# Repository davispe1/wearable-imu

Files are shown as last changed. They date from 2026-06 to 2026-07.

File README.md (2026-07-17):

# Wearable IMU — Project Master README

> Wearable IMU-based motion-capture system for **live upper-limb pose estimation**.
> Summer research project (IIT Chicago), with the goal of publishing.
>
> Single source of truth for the system architecture, hardware, communication design,
> processing pipeline, and repository structure.

### At a glance

| Node PCB (v1.0) | 5-DOF calibration / teleop rig |
|---|---|
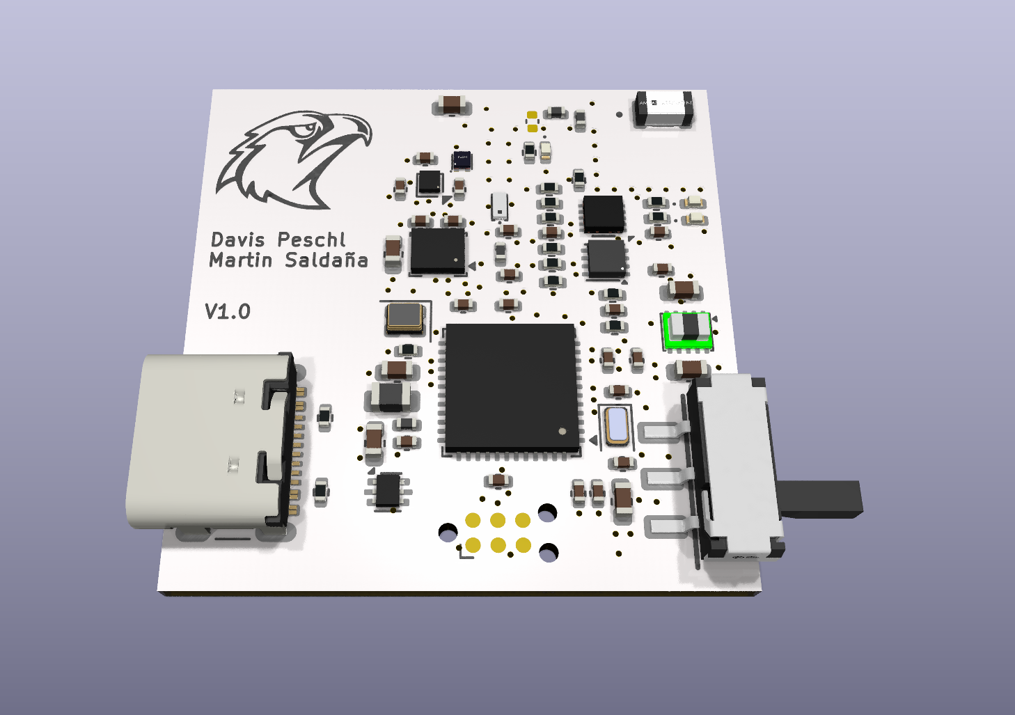
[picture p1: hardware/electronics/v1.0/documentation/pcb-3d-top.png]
PCB 3D top
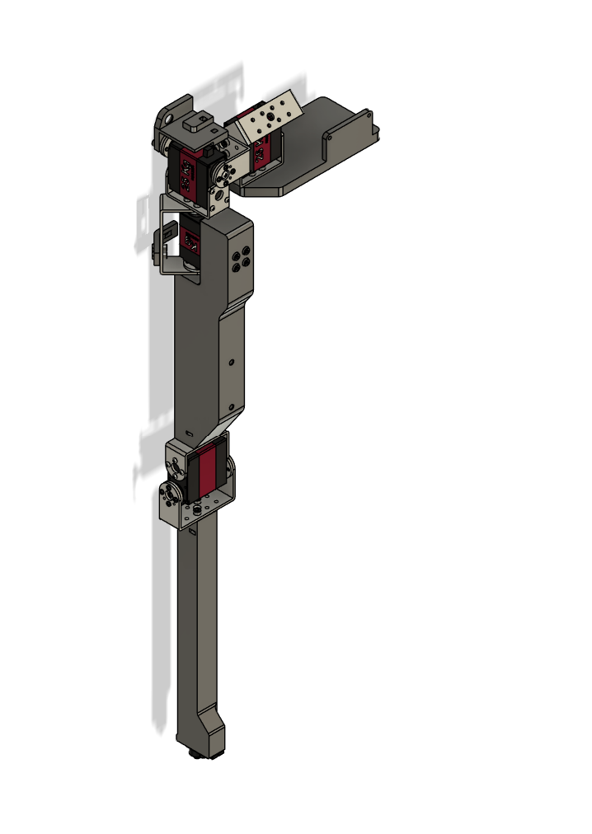
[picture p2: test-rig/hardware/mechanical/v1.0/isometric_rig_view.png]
5-DOF arm rig
|  |  |

**Left:** the wearable IMU node PCB (STM32WB55CEUx + DWM3000 + LSM6DSV16BXTR + BMM350).
**Right:** a separate parallel sub-project, [`test-rig/`](test-rig/README.md) — a
motorised 5-DOF arm used two ways: (1) **teleoperation demo**, driven live from the
wearable nodes, and (2) **calibration / ground truth**, moved through known joint
angles to validate the IMU pipeline's estimated angles against a known reference.

> **New to this project?** The actively maintained TODO / open-work list is
> [`docs/07-roadmap.md`](docs/07-roadmap.md) — start there to see what's done, what's
> open, and what's missing before picking up work.

---

## 1. Project overview

A network of small body-worn **IMU nodes** streams motion data to a **PC**, which reconstructs
and displays a live 3D skeleton of the upper limb. The design philosophy is **thin nodes,
heavy PC**: nodes only sample and transmit; all fusion, kinematics, and visualization run on
the PC — a discrete GPU is recommended for the live 3D visualization but not strictly required.

| Item | Decision (v1) |
|---|---|
| Focus | Upper limb |
| Output | Live joint angles + 3D skeleton visualization |
| Nodes | Scalable design; initial bring-up on **2 confirmed nodes** (wrist, clavicle), a 3rd (chest) possible, scaling to **6–8** |
| Sample rate | **100 Hz** target (hardware capable to 200 Hz) |
| Environment | Lab / bench (PC present in the room) |
| Compute | All heavy processing on the PC, **not** on a body MCU |
| Reference work | *Ultra Inertial Poser* (UIP), SIGGRAPH 2024 — see [References](#10-references) |

---

## 2. System architecture

All nodes use **identical hardware** (STM32WB55CEUx + DWM3000). One node is designated the
**master** purely in firmware. Because the boards are identical, multiple transport
topologies can be tested and compared on the same hardware (a useful experimental result).

### Primary topology

```mermaid
flowchart LR
    subgraph Body["On-body (wearable)"]
        N1["Sensor node 1<br/>WB55CE + DWM3000"]
        N2["Sensor node 2<br/>WB55CE + DWM3000"]
        N3["Sensor node N<br/>WB55CE + DWM3000"]
        M["Master node<br/>WB55CE + DWM3000"]
        N1 -- UWB --> M
        N2 -- UWB --> M
        N3 -- UWB --> M
    end
    M -- "BLE" --> PC["PC<br/>all processing + 3D viewer"]
    M -. "SWD / SWO (wired dev/recovery)" .-> PC
```

- **On-body UWB network** carries node data to the master, provides **time sync**, and
  (phase 2) provides **inter-node ranging** for drift correction.
- **Master node** aggregates all node data and is the single uplink to the PC.
- **PC** runs the full pipeline and the live visualization (stages detailed in [§6](#6-processing-pipeline-pc)).

> **v1 needs no Kalman filter.** Orientation → joint angles → DH skeleton → render is a
> complete working visualization. The EKF (with UWB distances) is a phase-2 enhancement
> for drift and position.

---

## 3. Transports & fallbacks

Every node has **two radios**: UWB for the on-body network (node → master, time sync,
ranging) and BLE for the master's wireless uplink to the PC. Paths to the PC:

| Layer | Path | Role |
|---|---|---|
| Live | BLE (master → PC, **host-native** Bluetooth) | Main wireless link |
| Wired | **SWD / SWO** via ST-LINK, or native USB (CDC) | Bench/dev + data recovery |

Notes:
- BLE uses **serial-over-BLE** (a transparent UART-style GATT service / NUS-equivalent), so
  it behaves like a wireless UART. **Decided: host-native Bluetooth** — the PC's own
  Bluetooth receives it, no extra receiver hardware.
- **Debug/data connection is a TC2030-IDC footprint** — bare pogo-pin pads on the PCB, not a
  soldered connector. A separate Tag-Connect TC2030 cable/clip clamps onto those pads from
  outside the board (to an ST-LINK) to make contact. Carries SWDIO/SWDCLK/SWO; SWO gives a
  one-way MCU→PC data channel (read via SWV tooling).
- **USB-C carries both charging and native USB data** (the WB55CEUx has native USB; a USB
  CDC stack is already in `firmware/USB_Device/`). The bring-up smoke test is likely read
  over this USB-CDC port, not SWO — **needs confirming**, since earlier wording assumed
  SWD/SWO was the only wired data path.
- RAM ring buffer (~seconds) covers jitter/retransmit; a >3–5 s dropout is treated as a
  compromised session regardless, so heavy persistence is unnecessary.

---

## 4. Hardware — Node BOM

Single identical board for every node. The architecturally significant parts:

| Function | Part | Notes |
|---|---|---|
| MCU | **STM32WB55CEUx** (UFQFPN48) | Dual-core: Cortex-M4 @ 64 MHz (application) + Cortex-M0+ @ 32 MHz (radio stack), Bluetooth 5.4 LE + 802.15.4, 512 KB flash, 256 KB SRAM, native USB. Drives DWM3000 over SPI. |
| IMU | **LSM6DSV16BXTR** | 6-axis, onboard SFLP sensor fusion. **I2C1, addr `0x6B`** (SDO pulled high) |
| Magnetometer | **BMM350** | Separate 3-axis → makes the node 9-DOF. **Decided: using it for v1** (not yet implemented in firmware — see [§7](#7-build-phases--roadmap)). **I2C1, addr `0x14`** (ADSEL pulled low) |
| UWB | **DWM3000** | Data transport + sync + (phase-2) inter-node ranging. SPI1 (only SPI sensor on the node — IMU and mag are both I2C) |

Full parts list (power management, connectors, battery, indicator, etc.) is in
[`hardware/electronics/v1.0/README.md`](hardware/electronics/v1.0/README.md#key-parts),
sourced directly from the fabricated board's BOM.

### PC-side hardware

| Function | Part | Notes |
|---|---|---|
| BLE receiver | **PC-native Bluetooth** | No extra receiver hardware |
| Compute | Any PC (a discrete GPU helps for the live 3D visualization, not required) | Runs full pipeline + visualization |

### Node PCB v1.0 — renders & board views

> Full detail (all four copper layers, schematic PDF, fab files) lives in
> [`hardware/electronics/v1.0/`](hardware/electronics/v1.0/README.md).
> Known antenna keepout issue on the DWM3000 — see [§7](#7-build-phases--roadmap) for the
> decision on whether that becomes a v1.1 bug-fix spin or gets folded into a v2.0 redesign,
> pending v1.0 bring-up results. See also
> [`hardware/electronics/CHANGELOG.md`](hardware/electronics/CHANGELOG.md).

| PCB 3D — top | PCB 3D — bottom |
|---|---|
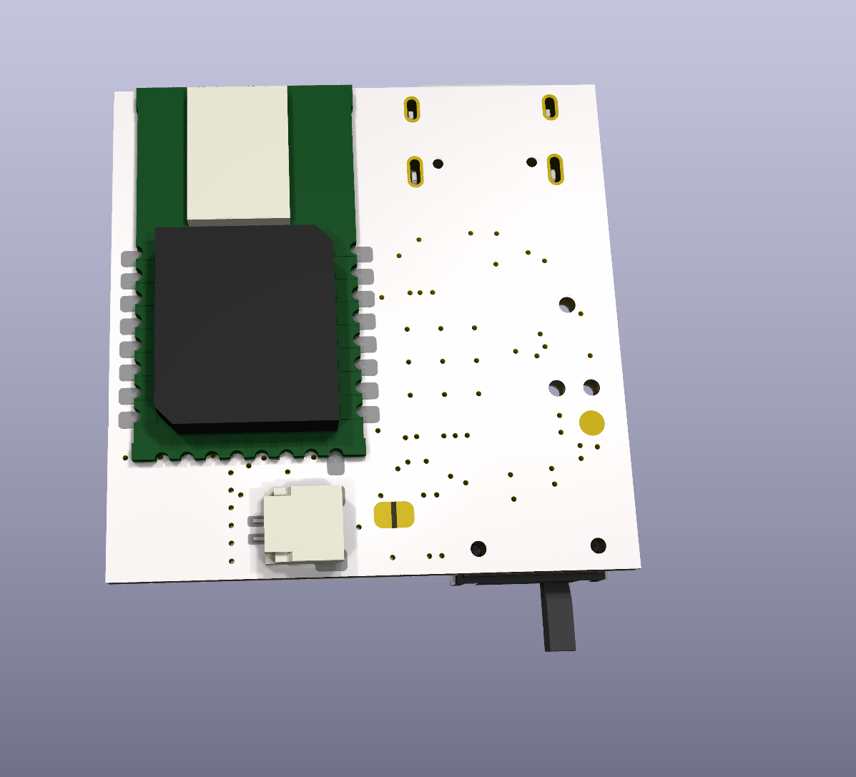
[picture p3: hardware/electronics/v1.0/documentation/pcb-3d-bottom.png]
PCB 3D bottom
| PCB 3D top |  |

| Assembled (exploded) | Worn on wrist |
|---|---|
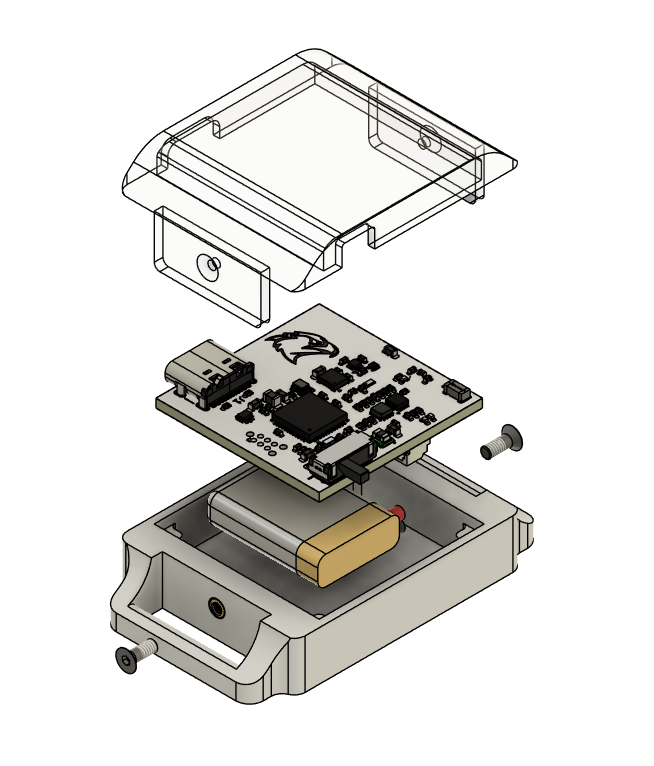
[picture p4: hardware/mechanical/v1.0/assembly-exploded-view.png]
Assembly exploded
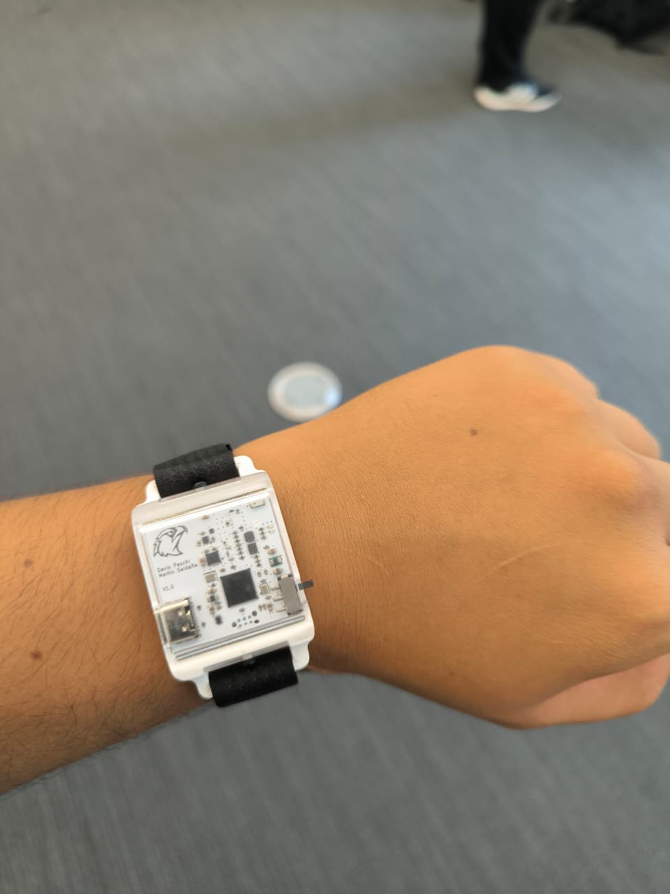
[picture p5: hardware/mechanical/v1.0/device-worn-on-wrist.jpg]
Worn on wrist
|  |  |

---

## 5. Communication & protocols

### Data format (per node, per sample)
- **Option A (preferred for the rig): raw 9-DOF** — accel(3) + gyro(3) + mag(3) + timestamp.
  Maximum flexibility; host does all fusion. ~40 bytes/sample.
- **Option B: SFLP quaternion** (from the LSM6DSV16B) + raw mag. Smaller, less host work.
- **Decision: open** (see [Open items](#11-open-items)). Magnetometer rate can be lower
  (e.g., 50–100 Hz).

> Bandwidth budgeting and UWB TDMA scheduling design used to be spelled out here with
> specific numbers, but neither BLE nor UWB has actually been tested on hardware yet — those
> numbers were pre-hardware-test estimates, not decisions. They now live in
> [`docs/04-firmware.md`](docs/04-firmware.md#tdma-frame-planned--not-implemented) (UWB
> scheduling/sync) and [`docs/03-communication.md`](docs/03-communication.md#6-bandwidth-check)
> (bandwidth), clearly marked as unvalidated estimates rather than settled numbers.

---

## 6. Processing pipeline (PC)

| Stage | Purpose | Maps to known technique |
|---|---|---|
| 0. Calibration | Sensor-to-segment alignment (T/N-pose) | — |
| 1. Orientation filter | accel+gyro(+mag) → world-frame quaternion | complementary / Madgwick / VQF (or use SFLP) |
| 2. Joint angles | relative rotation between adjacent segments | rotation matrices / quaternions |
| 3. EKF (phase 2) | fuse UWB inter-node distances → fix drift / get positions | Kalman filter (new) |
| 4. Forward kinematics | joint angles + segment lengths → 3D skeleton | **Denavit-Hartenberg** |
| 5. Visualization | live render of links/joints | 3D viewer |

- **v1 path:** stages 0 → 1 → 2 → 4 → 5 (no EKF).
- **Phase 2:** insert stage 3 (EKF + UWB ranging) for drift/position.
- A **synthetic data generator** (or arm-simulator rig) can drive the pipeline before
  hardware is ready.

---

## 7. Build phases / roadmap

1. **Firmware + data path** — node sampling, UWB schedule, master aggregation, PC ingest.
   Bring up over **SWD/SWO (wired)** first (familiar tooling), then add BLE as a parallel path.
2. **Visualization program** — orientation → joint angles → DH skeleton → live 3D render.
   Develop against **synthetic data** first. No Kalman filter needed.
3. **EKF** — learn the Kalman filter (from complementary-filter intuition) and fold in the
   UWB inter-node distances for drift/position.

> BLE de-risking: prove the entire system over wired (SWD/SWO) first; learn BLE in isolation
> on a NUCLEO-WB55RG with ST's serial-over-BLE example; then integrate with the wired path
> still available as a safety net.

### Parallel workstream — 5-DOF arm / test rig

A 5-DOF robotic arm mirroring human upper-limb kinematics. It's a single physical
rig serving **two purposes**:

1. **Teleoperation demo** — drive the arm live from the wearable IMU nodes.
2. **Calibration / ground-truth measurement** — move the arm through known joint
   angles and compare against the IMU pipeline's estimated angles, to quantify
   filter error.

5-DOF arm rig

Status: forward kinematics validated (MATLAB GUI); inverse kinematics implemented
but not yet validated; mechanical CAD for the rig itself in progress. Full detail
in [`docs/07-roadmap.md`](docs/07-roadmap.md#parallel-workstream--5-dof-arm-teleoperation--calibration-rig)
and [`test-rig/README.md`](test-rig/README.md).

---

## 8. Repository structure

Actual current tree (not aspirational — status noted per folder):

```
wearable-imu/
├── README.md                      # this file
├── CONTRIBUTING.md                # branch/tag/versioning conventions
├── docs/                          # markdown source of truth, one file per section
│   ├── 01-system-overview.md
│   ├── 02-hardware.md
│   ├── 03-communication.md        # authoritative wire protocol spec
│   ├── 04-firmware.md             # firmware architecture: CubeMX project + smoke test are
│   │                               #   real; packet/comms application layer still planned
│   ├── 05-host-pipeline.md
│   ├── 06-calibration.md
│   ├── 07-roadmap.md              # build phases, real done/not-done status, open items
│   ├── 08-appendices.md
│   └── 09-tools.md                # tools used to build/assemble hardware — incomplete
│
├── firmware/                      # STM32CubeIDE project for the STM32WB55CEUx node
│   ├── Core/                      # CubeMX-generated (HAL, startup, clock) — do not hand-edit
│   ├── Drivers/                   # CMSIS + STM32WBxx HAL
│   ├── Middlewares/ST/            # ST middleware
│   ├── ThirdParty/                # BMM350, lsm6dsv16bx vendor drivers
│   ├── USB_Device/                # USB CDC (virtual COM port) stack — native USB, not charging-only
│   └── *.ioc / *.ld               # CubeMX config + linker scripts
│   (application logic — packet serializer, UWB TDMA, BLE serial, role state
│    machines — not written yet; see docs/07-roadmap.md)
│
├── host/                          # Python package — the live PC pipeline
│   └── wearable_imu/
│       ├── ingest/                # serial / SWO readers + wire protocol codec (real, tested)
│       ├── sync/                  # timebase alignment
│       ├── orientation/           # filters (complementary / Madgwick / VQF) — stub
│       ├── kinematics/            # joint angles + DH forward kinematics — stub
│       ├── ekf/                   # phase 2: UWB-distance fusion — stub
│       ├── viz/                   # 3D skeleton viewer — stub
│       ├── sim/                   # synthetic data generator (real, drives dev without hardware)
│       ├── config.py
│       └── main.py
│
├── hardware/                      # physical design files — only place with version folders
│   ├── electronics/v1.0/          # node PCB: schematic, layout, fab files, renders
│   └── mechanical/v1.0/           # node enclosure: STEP/STL, assembly renders
│
├── simulation/scripts/            # 5-DOF arm kinematics (MATLAB) — FK validated, IK
│                                   # implemented pending validation. Not yet cross-linked
│                                   # into test-rig/ below.
├── test-rig/                      # ground-truth validation rig — mostly planned
│   └── hardware/mechanical/v1.0/  # rig arm CAD — in progress (the only real part so far)
│
├── calibration/                   # calibration routines + saved profiles — planned
└── tools/                         # flash/capture/calibrate/replay scripts — planned
```

---

## 9. Design decisions log (the "why")

- **Sensor selection, generally:** across the BOM, the guiding principle was to pick the
  most capable part available in its class at design time, not the cheapest one that
  technically works — this is a research/publication project, not a cost-optimized
  product, so headroom (accuracy, noise floor, ranging precision) was prioritized over
  BOM cost. The three sensing ICs below were each chosen on that basis:
  - **IMU = LSM6DSV16BXTR:** one of ST's most capable 6-axis parts at selection time —
    onboard SFLP (Sensor Fusion Low Power) hardware fusion can offload orientation
    estimation from the host, but is bypassable for a raw-data path if the host EKF is
    preferred instead. High ODR headroom (only 120 Hz is used here).
  - **Magnetometer = BMM350:** chosen for resolution/noise performance over cheaper
    3-axis parts, making the node 9-DOF. Populated on every board, but use is **optional**
    pending characterization of the lab's magnetic environment — indoor steel/motors can
    make magnetometer data actively worse than leaving it out.
  - **UWB = DWM3000:** the most capable UWB module available for this application —
    supports the newer 802.15.4z standard (better multipath resistance) with strong
    ranging accuracy. Chosen as the **sole radio** on the node: it replaces what would
    otherwise be a separate ranging radio, handling data transport, sub-ns time sync,
    and inter-node ranging in one part.
- **MCU = STM32WB55CEUx** (over the earlier L431 / U535): the master needs BLE; identical
  BLE-capable boards let any node be master and enable topology testing. Dual-core
  (Cortex-M4 app core + Cortex-M0+ radio stack core), ultra-low-power (good for a small
  battery), and has native USB (unlike the STM32WBA55 originally assumed during design —
  see the note in [§3](#3-transports--fallbacks) about reconciling the SWD/SWO-vs-USB wired
  data path now that native USB is actually available).
- **Master-aggregator + single BLE uplink** (vs UIP's per-node BLE): one BLE link instead of
  N (avoids PC multi-link flakiness) and gives tighter on-body sync.
- **BLE for the PC uplink, UWB kept on-body:** the master's single link to the PC is BLE
  (2.4 GHz, more robust to body blocking than UWB's 6.5–8 GHz); UWB is reserved for the
  on-body network — data transport to the master, time sync, and ranging — where it's
  irreplaceable.
- **PC does all heavy compute** (not a body MCU): the pipeline (and future ML) is GPU/
  desktop work, and PC-side iteration is far faster than reflashing firmware.
- **No on-node SD card or flash IC:** RAM buffer only; avoids tedious card extraction, and
  the fabricated v1.0 board doesn't populate a flash chip at all — recovery happens over
  SWD (or USB, pending the reconciliation above).
- **100 Hz for v1:** matches UIP and is sufficient for full-body pose; keeps BLE bandwidth
  comfortable.

---

## 10. References

- **[Ultra Inertial Poser (UIP), SIGGRAPH 2024](https://siplab.org/projects/UltraInertialPoser)**
  (Armani, Qian, Jiang, Holz — [ACM DL](https://dl.acm.org/doi/10.1145/3641519.3657465),
  [arXiv](https://arxiv.org/abs/2404.19541),
  [code](https://github.com/eth-siplab/UltraInertialPoser)) — sparse body-worn IMU + UWB
  inter-node ranging, fused on a host with VQF orientation, per-pair EKF, an LSTM + graph-conv
  network, and a physics dynamics optimizer to produce full-body pose.
  - **This project mirrors** the IMU + UWB sensing approach and the "thin nodes, host does
    the work" philosophy.
  - **This project differs:** adds a magnetometer (9-DOF vs UIP's 6-DoF); uses a
    master-aggregator UWB→BLE topology (vs UIP's per-node BLE to host); focuses on upper-limb
    joint angles + live visualization for v1; EKF/ranging is a phase-2 enhancement.

---

## 11. Open items

**The actively maintained TODO / open-work list lives in
[`docs/07-roadmap.md`](docs/07-roadmap.md)** — its "Open items", "Hardware revisions", and
"Known gaps" sections are the source of truth for what's decided, what's still open, and
what's missing (including firmware, UWB/BLE testing, the test-rig end-effector adapter, and
the onboarding doc for new students). This section is intentionally just a short pointer
rather than a second list, to avoid the two drifting out of sync.

Top-level decisions still open, at a glance:
- **Data format:** raw 9-DOF vs SFLP quaternion + raw mag.
- **Magnetometer:** whether to use it (characterize the lab's magnetic environment first;
  hardware is populated either way).
- **Sample rate:** confirm 100 Hz (vs 200 Hz).

---

## How to use this document

This README and the `docs/` folder are the **markdown source of truth** (versioned in git;
diagrams in **Mermaid** so they edit as text and render on GitHub). For a polished copy for
the team/professor, export markdown → Word/PDF with Pandoc rather than hand-maintaining a
second copy.

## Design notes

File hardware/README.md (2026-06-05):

# hardware/

Physical design files. **This is the only place in the repo with version folders.**

Hardware revisions are discrete fabricated artifacts — you'll have v1.0 boards in hand
while designing v1.1, so both must coexist. Version folders (`v1.0/`, `v1.1/`, …) make
that explicit. Git tags tie a code release to the hardware revision that belongs with it.

## Structure

```
hardware/
├── electronics/
│   ├── v1.0/          ← schematic, layout, BOM, fab files for board rev 1.0
│   └── CHANGELOG.md
└── mechanical/
    ├── v1.0/          ← STEP / STL / CAD files for case rev 1.0
    └── CHANGELOG.md
```

## Adding a new hardware revision

1. Copy the previous version folder (`cp -r v1.0 v1.1`).
2. Make your changes inside `v1.1/`.
3. Add an entry to `CHANGELOG.md`.
4. When a firmware/host release is tied to this hardware rev, create a git tag
   `imu-vX.Y.Z` that documents which hardware folder it targets.

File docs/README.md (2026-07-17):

# docs/

Deep-dive documentation, one file per section. The top-level `README.md` is
the executive summary and source of truth for architecture decisions; these
files expand on each area.

| File | Contents |
|---|---|
| [01-system-overview.md](01-system-overview.md) | Goals, topology, design philosophy |
| [02-hardware.md](02-hardware.md) | Node BOM, host hardware, PCB notes |
| [03-communication.md](03-communication.md) | Protocols, packet formats, bandwidth |
| [04-firmware.md](04-firmware.md) | Firmware architecture, TDMA schedule, drivers |
| [05-host-pipeline.md](05-host-pipeline.md) | Processing stages, orientation filter, DH kinematics |
| [06-calibration.md](06-calibration.md) | T-pose / N-pose procedure, saved profiles |
| [07-roadmap.md](07-roadmap.md) | Build phases, open items, milestones |
| [08-appendices.md](08-appendices.md) | References, glossary, data-sheet links |
| [09-tools.md](09-tools.md) | Tools used to build/assemble the hardware — incomplete |

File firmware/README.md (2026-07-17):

# firmware/

Node firmware for the STM32WB55CEUx. **Git-versioned — no version folders here.**
Use `git tag imu-vX.Y.Z` to mark releases and tie them to a hardware revision.

## Structure

Standard STM32CubeIDE project layout, generated from `wearable IMU.ioc`:

```
firmware/
├── Core/            # CubeMX-generated — do NOT edit by hand; regenerate from .ioc
│   ├── Inc/, Src/, Startup/
├── Drivers/
│   ├── CMSIS/                   # ARM CMSIS
│   └── STM32WBxx_HAL_Driver/    # ST HAL
├── Middlewares/ST/               # ST middleware (e.g. BLE stack support)
├── ThirdParty/
│   ├── BMM350/                  # magnetometer vendor driver
│   └── lsm6dsv16bx/             # IMU vendor driver
├── USB_Device/                   # USB CDC (virtual COM port) stack — the WB55CEUx has native USB
├── *.ld                          # linker scripts
└── wearable IMU.ioc              # CubeMX config (source of truth for Core/)
```

Application logic (role state machines, UWB TDMA, BLE serial, sensor glue,
power management) isn't written yet — only the CubeMX-generated skeleton
exists so far. An earlier scaffolded `App/`, `Comms/`, `Drivers/{dwm3000,
lsm6dsv16b,...}`, `Sensors/`, `Power/` layout was removed in favor of this
generated structure; expect the application code to land inside `Core/Src/`
or new folders alongside it as it's written.

## Bring-up order

1. Generate `Core/` from STM32CubeMX for the STM32WB55CEUx.
2. Bring up SWD/SWO wired link first.
3. Add UWB TDMA (data + sync + ranging).
4. Add BLE serial-over-BLE uplink.

## Building

TODO: STM32CubeIDE project setup. Toolchain: arm-none-eabi-gcc.

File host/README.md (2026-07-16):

# host/

PC-side processing pipeline and 3D visualizer. **Git-versioned — no version folders.**
Tag releases as `imu-vX.Y.Z` alongside the firmware and hardware revision they target.

## Structure

```
host/wearable_imu/
├── ingest/       # serial / BLE / SWO readers → raw sample stream
├── sync/         # multi-node timestamp alignment
├── orientation/  # accel+gyro(+mag) → world-frame quaternion
├── kinematics/   # joint angles + Denavit-Hartenberg forward kinematics
├── ekf/          # phase 2: UWB-distance fusion for drift/position
├── viz/          # live 3D skeleton viewer
├── sim/          # synthetic data generator (develop pipeline without hardware)
├── config.py     # runtime configuration (sample rate, node count, data format …)
└── main.py       # entry point
```

## Setup

```bash
python -m venv .venv
source .venv/bin/activate   # Windows: .venv\Scripts\activate
pip install -r requirements.txt
```

## Running (Phase 1 — ingest path is live)

The protocol/ingest path is stdlib-only, so it runs without installing anything:

```bash
# from host/
py -m wearable_imu.main --sim --seconds 3          # synthetic data through the real codec
py -m wearable_imu.main --sim --capture cap.bin --seconds 5   # write a capture
py -m wearable_imu.main --replay cap.bin           # replay a capture file
py -m wearable_imu.main                             # live: config.TRANSPORT serial port
```

## Tests

```bash
py host/tests/test_protocol.py     # round-trip, fragmentation, resync, golden vector
```

The golden vector in the test is byte-identical to `firmware/.../packet_selftest.c`,
so the firmware and host encoders are locked together.

## Development order (README §7)

1. Drive pipeline with `sim/` synthetic data — no hardware needed.
2. Add `ingest/` SWO reader for wired bring-up.
3. Add `ingest/` BLE reader once firmware BLE is ready.

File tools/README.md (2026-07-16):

# tools/

Utility scripts for flashing, data capture, and calibration.

**Status: planned, not started.** Nothing in this folder is implemented yet;
the table below is the intended scope, not an inventory.

| Script (planned) | Purpose |
|---|---|
| `flash.py` | Flash a node via ST-LINK (wraps openocd / STM32CubeProgrammer) |
| `capture.py` | Capture a raw SWO session to file for offline replay |
| `calibrate.py` | Run the T/N-pose calibration wizard and save a profile |
| `replay.py` | Feed a captured session file through the host pipeline |

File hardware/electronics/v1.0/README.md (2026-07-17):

# electronics / v1.0

Node PCB — revision 1.0. 4-layer board (F.Cu, In1.Cu, In2.Cu, B.Cu).

> **Known issue, fix path pending v1.0 evaluation:** the DWM3000 UWB antenna
> placement doesn't fully follow Qorvo's layout guidelines (clearance/keepout,
> feed line length), which may affect range/link margin. Whether this becomes a
> v1.1 placement-only fix or gets folded into a v2.0 redesign depends on how
> v1.0 performs in bring-up. See `../CHANGELOG.md` and `docs/07-roadmap.md`.

## Contents

- `wearable_IMU.kicad_sch` — schematic (source)
- `wearable_IMU.kicad_pcb` — layout (source)
- `wearable_IMU.kicad_pro` / `.kicad_prl` — project files
- `documentation/` — exported images (below) + `schematic.pdf`
- `jlcpcb/` — fab outputs: `gerber/` (raw Gerbers + drill files), `production_filesV1.0/`
  (BOM, pick-and-place, zipped Gerbers — the JLCPCB submission set), `project.db`
- `fabrication-toolkit-options.json` — KiCad fabrication-toolkit plugin export settings
- The PCB's 3D model (`PCB.step`) lives in `../../mechanical/v1.0/` alongside the
  enclosure — kept in one place instead of duplicated here

Cleaned up (untracked, safe to regenerate/ignore): KiCad's local autosave/history
folders (`.history/`, `.history_trim/` — an embedded git history plugin, ~290 MB),
`wearable_IMU-backups/` (autosave zips), a stale `production/` test export
("prueba1"), an empty `jlcpcb/production_files/`, 0-byte `.rpt` temp files, and
KiCad's `.lck` lock files. Added patterns to `.gitignore` so these don't come back.

## Key parts

Straight from the fabricated board's BOM (`jlcpcb/production_filesV1.0/BOM-wearable_IMU.csv`):

| Function | Part |
|---|---|
| MCU | STM32WB55CEUx |
| IMU | LSM6DSV16BXTR |
| Mag | BMM350 |
| UWB | DWM3000 |
| SMPS | TPSM828224 |
| Charger | BQ25185 |
| Fuel gauge | MAX17048G+T10 |
| Power btn | STM6601BM2DDM6F |

No flash IC is populated — RAM buffering only, no on-node session logging.

## Fabrication

Board fabricated and assembled via **JLCPCB** (PCBA — SMT assembly included, not just bare
board fab). Production files were exported from KiCad using the **fabrication-toolkit**
plugin (`fabrication-toolkit-options.json` holds its export settings).

To re-order or fab a new revision:
1. Open `wearable_IMU.kicad_pro` in KiCad, update as needed.
2. Run the fabrication-toolkit plugin to regenerate `jlcpcb/production_filesV1.0/` (or a new
   `production_filesVX.Y/` for a new revision) — Gerbers, `BOM-wearable_IMU.csv`,
   `CPL-wearable_IMU.csv` (component placement).
3. Upload the zipped Gerbers + BOM + CPL to JLCPCB's PCBA order flow.

## Board renders & layers

**3D views**

| Top | Bottom |
|---|---|
| PCB 3D top | PCB 3D bottom |

**Copper layers** (top → bottom of stack)

| F.Cu (top) | In1.Cu | In2.Cu | B.Cu (bottom) |
|---|---|---|---|
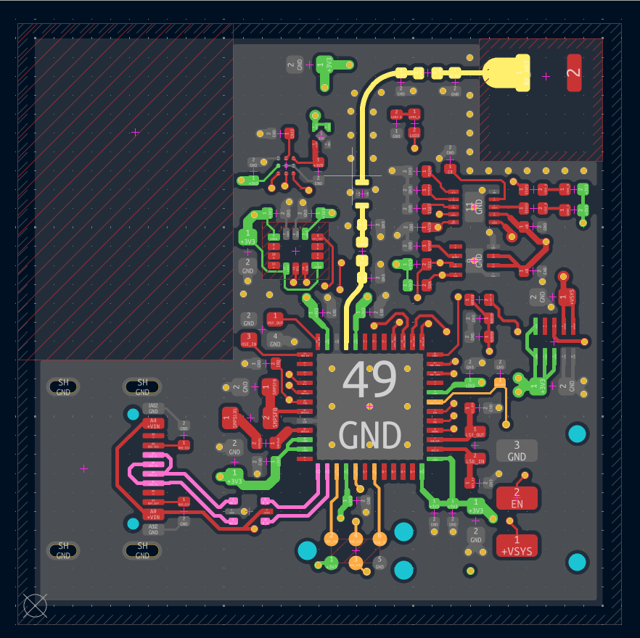
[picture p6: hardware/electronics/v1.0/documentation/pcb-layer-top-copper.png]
Top copper
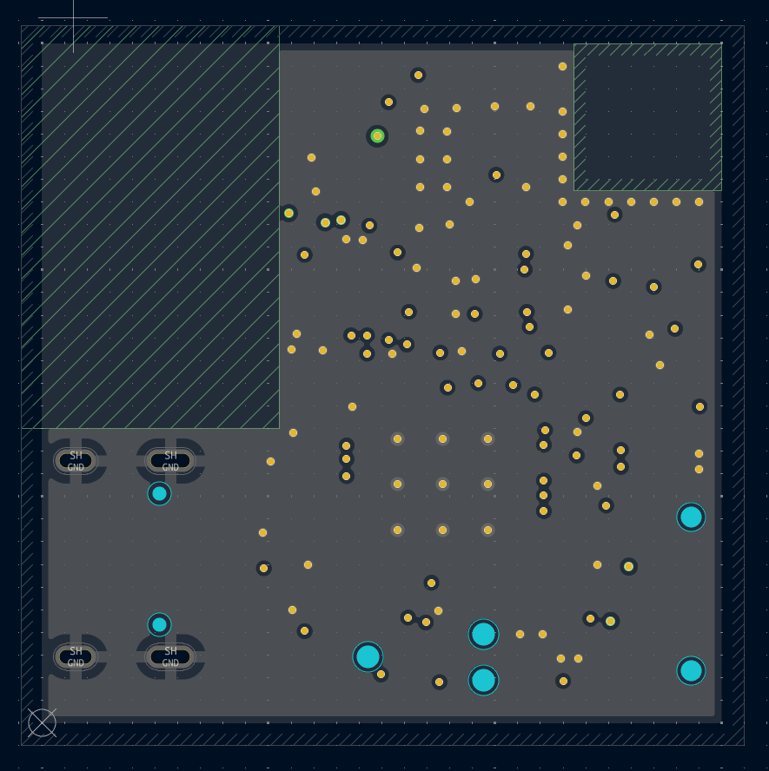
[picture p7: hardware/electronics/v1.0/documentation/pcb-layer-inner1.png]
Inner 1
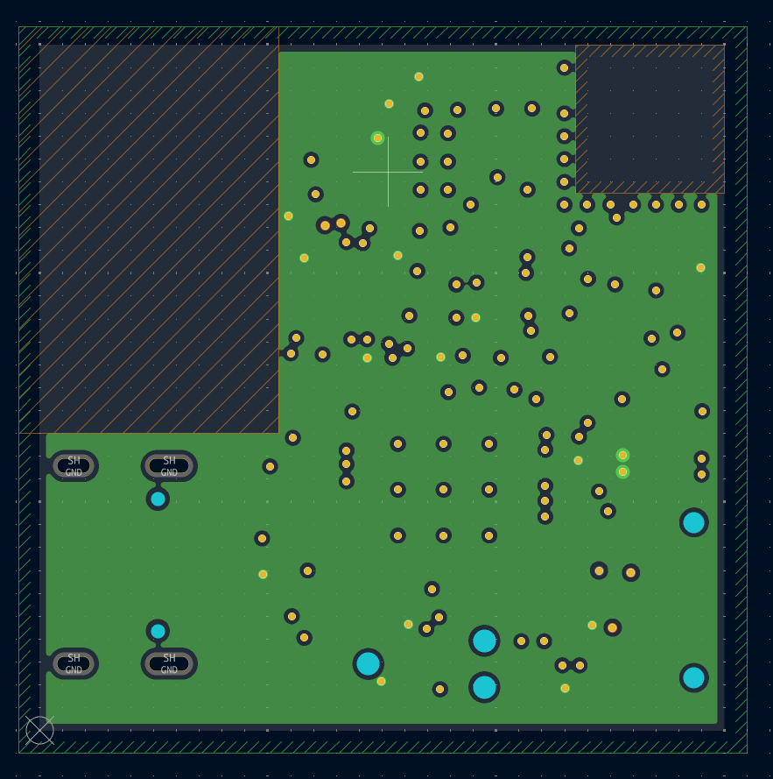
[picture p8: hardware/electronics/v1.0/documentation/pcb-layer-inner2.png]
Inner 2
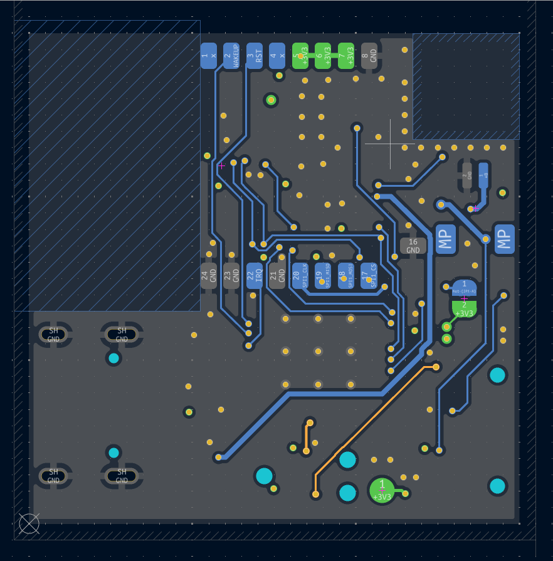
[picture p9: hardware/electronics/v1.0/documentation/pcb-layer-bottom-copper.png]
Bottom copper
|  |  |  |  |

**Schematic:** [`documentation/schematic.pdf`](documentation/schematic.pdf)

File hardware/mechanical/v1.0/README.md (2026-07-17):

# mechanical / v1.0

Node enclosure — revision 1.0.

## Contents

- `PCB.step` — PCB STEP file (for ECAD/enclosure co-design)
- No printable enclosure file in the repo currently — the STLs (`CASE.stl`,
  `case1.stl`) were removed as not needed. The renders below still document
  what the design looked like.

## Assembly

| Orthographic (front/top/side) | Exploded (isometric) | Exploded (lateral) |
|---|---|---|
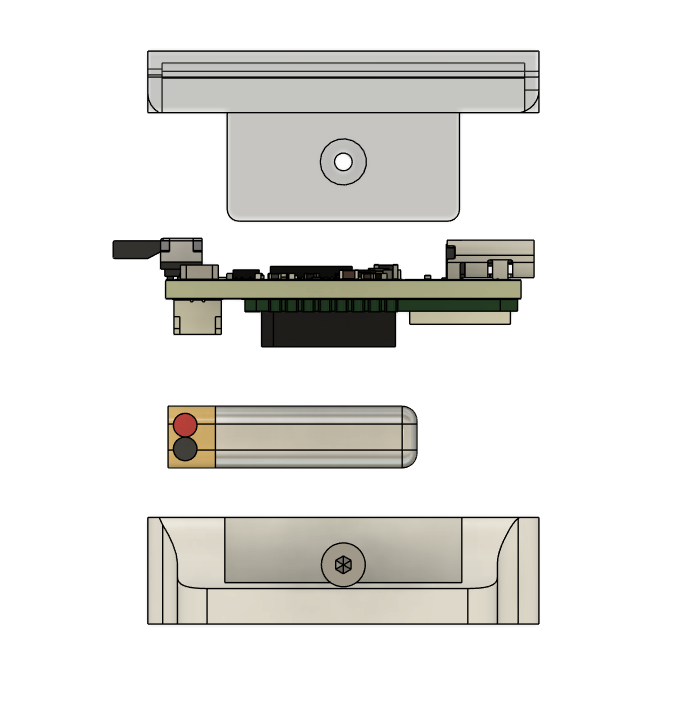
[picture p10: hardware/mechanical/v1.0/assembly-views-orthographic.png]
Assembly orthographic
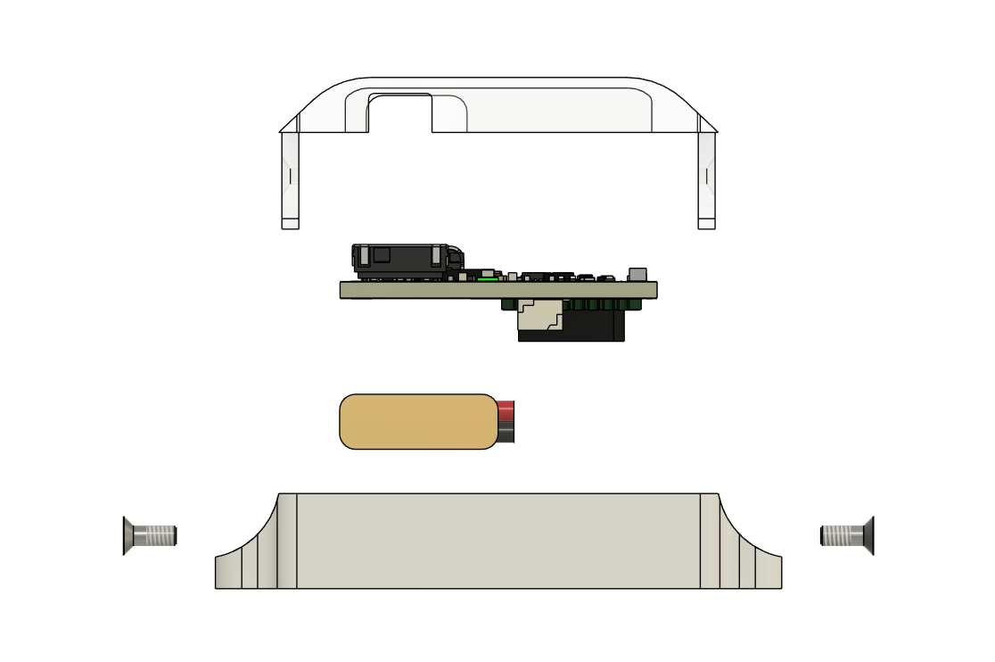
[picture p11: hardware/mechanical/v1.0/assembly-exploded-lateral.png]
Assembly exploded lateral
|  | Assembly exploded |  |

**On device:**

Worn on wrist

## Design notes

3-part shell (top cover + base) with strap slots, USB-C cutout, and a
power-button cutout. Case + battery + PCB assemble as shown above.

TODO: dimensions writeup, mounting/strap interface details, connector cutout
tolerances.

## Bill of materials

**Pending** — see [07-roadmap.md](../../../docs/07-roadmap.md).

## Fabrication

**Pending** — see [07-roadmap.md](../../../docs/07-roadmap.md).

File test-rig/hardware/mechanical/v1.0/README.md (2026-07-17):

# test-rig / mechanical / v1.0

5-DOF arm rig — mechanical design, revision 1.0.

## Contents

- `RIG.f3z` — Fusion 360 archive (native source)
- `isometric_rig_view.png` — isometric render

Rig isometric view

Servo-driven links matching the 5-DOF DH model used in
[`simulation/scripts/shoulder_arm_fk.m`](../../../../simulation/scripts/shoulder_arm_fk.m)
and `shoulder_arm_ik.m`.

TODO: STEP/STL export for non-Fusion viewers, dimensions writeup, servo/mount BOM.

## Known gaps

- **End-effector adapter (missing):** no piece exists yet to physically mount a
  wearable IMU node at the rig's end effector — needed for both the teleop and
  calibration/ground-truth use cases. Not designed.
- **Wearable IMU rig variant ("fork") — not yet in this repo:** a modified
  version of the wearable IMU enclosure exists (built to attach to the rig
  instead of being worn), but its CAD/design files haven't been added here yet.
- **`arm` piece needs reprinting:** the physical `arm` part currently on the lab
  rig needs a fresh print (current one is out of date / not usable as-is).

## Bill of materials

**Pending** — see [07-roadmap.md](../../../../docs/07-roadmap.md).

## Fabrication

**Pending** — see [07-roadmap.md](../../../../docs/07-roadmap.md).

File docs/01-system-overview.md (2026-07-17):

# 01 — System Overview

> Expand on README §1–2. Fill in as design decisions are finalised.

## Goals

- Live upper-limb pose estimation from body-worn IMU nodes.
- 100 Hz sample rate, sub-millisecond on-body time sync.
- Thin nodes (sample + transmit only); all fusion/kinematics/viz on the host PC.

## Topology

See README §2 (Mermaid diagrams). Key points:

- N identical STM32WB55CEUx + DWM3000 nodes. One is designated **master** in firmware.
- On-body UWB bus: data + time-sync + inter-node ranging in a TDMA frame.
- Single BLE uplink from master to host.

## Design philosophy

- **Thin nodes, heavy host** — avoids reflashing for algorithm changes.
- **Identical hardware** — any node can be master; simplifies spares and testing.
- **Wired-first bring-up** — SWD/SWO before BLE; de-risks each layer independently.

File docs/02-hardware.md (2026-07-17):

# 02 — Hardware

> Expand on README §4. Add pin mappings, power tree, layout notes here.

## Node BOM (v1.0)

See README §4 for the full table. Key parts:

- MCU: STM32WB55CEUx (UFQFPN48), dual-core Cortex-M4 (64 MHz) + Cortex-M0+ (32 MHz),
  512 KB flash, 256 KB SRAM, native USB
- IMU: LSM6DSV16BXTR (6-axis + onboard SFLP), I2C
- Mag: BMM350 (populated, use open — see open items), I2C
- UWB: DWM3000 (SPI from WB55CEUx — the only SPI sensor on the node)
- No on-node flash IC (confirmed against the fabricated PCB's BOM — not populated)
- Charger: BQ25185 | Fuel gauge: MAX17048 | SMPS: TPSM828224

## Interfaces

| Peripheral | WB55CEUx interface | Notes |
|---|---|---|
| DWM3000 | SPI1 | IRQ pin not yet assigned in firmware |
| LSM6DSV16BXTR | I2C1, addr `0x6B` | SDO pin pulled high. INT1/INT2 |
| BMM350 | I2C1, addr `0x14` | ADSEL pin pulled low |
| BQ25185 | I2C, bus not yet assigned in firmware | |
| MAX17048 | I2C, bus not yet assigned in firmware | |
| SWD/SWO | SWDIO/SWDCLK/SWO | TC2030-IDC footprint (Tag-Connect) — bare pogo-pin pads, no on-board connector; mates with a separate TC2030 cable/clip |
| USB | Native USB (CDC stack present in firmware) | See README §3 — needs reconciling with the SWD/SWO wired-data-path assumption now that native USB is confirmed |

## Power tree

TODO: fill in from schematic (TPSM828224 → 3V3 rail; BQ25185 USB-C charging).

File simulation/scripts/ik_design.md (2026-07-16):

# Inverse Kinematics — `shoulder_arm_ik.m`

Design document for the 5-DOF analytical inverse kinematics solver.

---

## 1. Goal

Given a desired end-effector **position** (x, y, z) and **orientation** (ZYX Euler angles: yaw, pitch, roll), find all valid joint angle configurations `[q1, q2, q3, q4, q5]` that reach that target. Since the arm has only 5 DOF, it cannot independently satisfy all 6 constraints (3 position + 3 orientation). The solver uses position + 2 orientation components as hard constraints, then ranks solutions by how closely the remaining orientation component matches the input.

---

## 2. DH Table (current, from `shoulder_arm_fk.m`)

| Joint | theta_offset (deg) | alpha (deg) | a (mm) | d (mm)  | Description |
|---:|---|---|---|---|---|
| 1 | 0 | 90 | 0 | 55.4 | Shoulder flexion / extension |
| 2 | 90 | 90 | 0 | 0 | Shoulder abduction / adduction |
| 3 | -90 | -90 | 0 | 283.5 | Shoulder internal / external rot.  |
| 4 | 0 | 90 | 0 | 0 | Elbow flexion / extension |
| 5 | 90 | 0 | 30 | 257 | Forearm pronation / supination |

**Key dimensions:**
- `d1 = 55.4 mm` — shoulder offset (lateral, along initial Z)
- `d3 = 283.5 mm` — upper arm length (shoulder to elbow)
- `d5 = 257 mm` — forearm length (elbow to wrist)
- `a5 = 30 mm` — wrist lateral offset ("watch" side)

---

## 3. Kinematic Structure

Joints 1–3 form a **spherical shoulder** — three revolute axes intersecting at a point offset `d1 = 55.4 mm` from the base along Z. This allows **wrist-point decoupling**: the position problem (joints 1, 2, 4) can be separated from the orientation problem (joints 3, 5).

### 3.1 Decoupling Strategy

```
[Position]    → Solve for wrist center location → q1, q2, q4
[Orientation] → Solve for rotation around arm axis → q3, q5
```

**Step A — Wrist center:**
The wrist center `p_wc` is the origin of frame 4 (elbow-to-wrist intersection). Given the desired EE position `p_ee` and orientation `R_ee`:

```
p_wc = p_ee - d5 * R_ee(:,3) - a5 * R_ee(:,1)
```

This removes the forearm length and wrist offset from the target, leaving the point that joints 1–2–4 must reach.

**Step B — Shoulder angles (q1, q2) and elbow (q4):**
With `p_wc` known, project onto the shoulder geometry:

1. **q1 (shoulder flex/ext):** from the projection of `p_wc` onto the XZ plane (after removing the `d1` offset)
2. **q2 (shoulder abd/add):** from the elevation angle of `p_wc` relative to the shoulder axis
3. **q4 (elbow flex/ext):** from the triangle formed by `d3` (upper arm), the distance from shoulder to `p_wc`, using the law of cosines. This gives **two solutions**: elbow-up and elbow-down.

**Step C — Rotation angles (q3, q5):**
With q1, q2, q4 known, compute `R_0_to_3` (rotation from base to frame 3) and `R_4_to_5` (frame 4 to 5). Then:

```
R_3_to_4 = R_0_to_3' * R_ee * R_5_to_ee'
```

Extract q3 and q5 from this intermediate rotation matrix.

---

## 4. Solution Pipeline

The MATLAB file will execute the following steps in order:

### Step 1 — Input & Workspace Check
- User enters: `[x, y, z]` (mm) and `[yaw, pitch, roll]` (deg, ZYX Euler)
- Convert Euler angles to rotation matrix `R_ee`
- Compute wrist center `p_wc`
- Check reachability: `norm(p_wc - p_shoulder) <= d3 + d5` (max reach) and `>= |d3 - d5|` (min reach)
- If unreachable → display error, stop

### Step 2 — Analytical IK (enumerate all solutions)
- Solve q4 from law of cosines → 2 solutions (elbow-up / elbow-down)
- For each q4, solve q1, q2 → may produce sign ambiguities (2 branches)
- For each (q1, q2, q4), solve q3, q5 from orientation
- Total: up to **4 candidate solutions**

### Step 3 — Display all raw solutions
- Show a table of all candidate `[q1, q2, q3, q4, q5]` (degrees)
- Label each with its configuration (e.g., "elbow-up", "elbow-down")

### Step 4 — Joint limit filter
- Remove any solution where a joint exceeds its physiological limit
- Mark filtered-out solutions in the table (grayed out or red)
- If all filtered → display warning

### Step 5 — Rank by orientation match
- Position will already be accurate (3 joints dedicated to it), so ranking is purely by **orientation fit**
- For each surviving solution, compute FK to get the actual EE orientation `R_actual`
- Compare `R_actual` vs. the full input `R_ee`:

```
ori_error = norm(logm(R_actual' * R_ee))   % geodesic distance on SO(3)
```

- Rank solutions by smallest orientation error only
- The best match is the configuration whose orientation (driven by q3, q5) aligns most closely with the full 3-axis IMU orientation input

### Step 6 — Visualize best solution
- Draw the arm in the selected configuration (reuse FK + drawing code from `shoulder_arm_fk.m`)
- Draw **target reference arrows** at the desired `[x, y, z]`: RGB arrows (X=red, Y=green, Z=blue) showing the desired orientation frame
- Draw the actual EE frame on the arm for visual comparison
- Display: joint angles, position error (mm), orientation error (deg)

---

## 5. GUI Layout

```
+---------------------------+--------------------------------------+
|  INPUT                    |                                      |
|  Position [x, y, z] mm   |                                      |
|  Orientation [Y, P, R] ° |           3D VISUALIZATION           |
|  [Solve] button           |                                      |
|                           |   - Arm in solved configuration      |
|  RESULTS TABLE            |   - Target frame (RGB arrows)        |
|  Solution | q1..q5 | err  |   - Body context (torso + FRONT)     |
|  #1  ✓    | ...    | 0.3° |   - Shoulder disc                    |
|  #2  ✗    | ...    | lim  |                                      |
|  #3  ✓    | ...    | 4.1° |                                      |
|                           |                                      |
|  SELECTED: #1             |                                      |
|  Pos error: 0.01 mm       |                                      |
|  Ori error: 0.3°          |                                      |
+---------------------------+--------------------------------------+
```

- No joint sliders (IK drives the angles, not the user)
- Clicking a row in the results table switches the visualization to that solution
- Solutions that violate joint limits are shown but grayed out

---

## 6. File Structure

Single file: `simulation/scripts/shoulder_arm_ik.m`

```
shoulder_arm_ik()
├── CONFIG (DH table, joint limits, mount_angle_deg — copied from FK file)
├── GUI setup (input fields, results table, 3D axes)
├── solve_ik(p_target, R_target)
│   ├── workspace_check()
│   ├── solve_position()      → q1, q2, q4 candidates
│   ├── solve_orientation()   → q3, q5 for each candidate
│   └── returns all solutions
├── filter_and_rank(solutions, R_target)
│   ├── joint_limit_filter()
│   ├── orientation_ranking() → geodesic distance
│   └── returns ranked list
├── forward_kinematics(q)     → reused from FK file
├── draw_robot(q)             → reused from FK file
├── draw_target_frame(p, R)   → RGB arrows at target
└── drawing helpers           → reused from FK file
```

---

## 7. Edge Cases to Handle

- **Singular configurations:** wrist center on the shoulder Z-axis (q1 undefined) — use atan2 fallback
- **At reach limit:** elbow fully extended, only 1 solution instead of 2
- **No valid solutions:** all candidates violate joint limits — show warning, display closest invalid solution dimmed
- **Orientation mismatch:** large gap between best solution's orientation and input — show warning if > 15°

---

## 8. Future Extensions (not implemented now)

- Quaternion input (replace Euler → rotation matrix conversion)
- Real-time IMU stream: solve IK each frame, use continuity filter to pick smoothest solution
- Animation: interpolate between current and solved configuration
- Left/right arm toggle with mirrored DH

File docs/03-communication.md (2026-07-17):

# 03 — Communication

> **Authoritative wire-protocol spec.** The host parser
> (`host/wearable_imu/ingest/protocol.py`) implements this document and is real/tested.
> The firmware serializer is **not implemented yet** — no `packet.c` exists (see
> [07-roadmap.md](07-roadmap.md)); once written, it should be the firmware twin of
> the host parser. If you change the protocol, change it here first, then both ends,
> then bump `PROTO_VERSION`.

## 0. Conventions

- **Endianness:** little-endian for all multi-byte fields (STM32 and x86 are both LE).
- **Integers:** unsigned unless noted; sensor samples are signed `int16` raw counts.
- **Units on the wire:** raw ADC counts (not physical units). The host applies scale +
  bias — keeps nodes thin. Scale factors live in `protocol.py` and must match the
  full-scale settings the firmware configures (see §4).

## 1. Frame structure

Every frame on every transport (SWO, BLE serial, USB CDC, file replay) uses this envelope:

```
┌────────────┬──────┬─────────────────────────────────────────────┐
│ Field      │ Size │ Notes                                        │
├────────────┼──────┼─────────────────────────────────────────────┤
│ SYNC0      │ 1    │ 0xAA                                          │
│ SYNC1      │ 1    │ 0x55                                          │
│ VERSION    │ 1    │ PROTO_VERSION = 0x01                          │
│ MSG_TYPE   │ 1    │ see §2                                        │
│ PAYLOAD_LEN│ 2    │ uint16 LE — number of payload bytes          │
│ PAYLOAD    │ var  │ PAYLOAD_LEN bytes (§3)                        │
│ CRC16      │ 2    │ uint16 LE, CRC-16/CCITT-FALSE over            │
│            │      │   VERSION..last payload byte (excludes SYNC)  │
└────────────┴──────┴─────────────────────────────────────────────┘
```

Header is 6 bytes, trailer (CRC) is 2 bytes → 8 bytes of envelope overhead per frame.

**CRC-16/CCITT-FALSE:** poly `0x1021`, init `0xFFFF`, no reflection, no final XOR.
Covers `VERSION, MSG_TYPE, PAYLOAD_LEN, PAYLOAD` so a corrupted length is also caught.

**Resync:** a reader scans for `AA 55`. On CRC failure it discards one byte past the false
`AA 55` and rescans — a corrupted/misaligned stream re-locks within a few bytes.

## 2. Message types

| Value | Name | Meaning |
|---|---|---|
| 0x01  | `MSG_IMU` | One or more node IMU samples (§3.1) |
| 0x02  | `MSG_RANGE` | UWB inter-node ranges (§3.2) |
| 0x10  | `MSG_STATUS` | Reserved — battery / link stats (future) |

## 3. Payloads

### 3.1 `MSG_IMU`

```
┌────────────┬──────┬───────────────────────────────────────────┐
│ FRAME_SEQ  │ 2    │ uint16 LE — increments per emitted frame    │
│ FORMAT     │ 1    │ 0 = RAW_9DOF, 1 = SFLP_QUAT                  │
│ NODE_COUNT │ 1    │ number of node records that follow          │
│ records[]  │ var  │ NODE_COUNT × node record                    │
└────────────┴──────┴───────────────────────────────────────────┘
```

**Node record — FORMAT 0 (RAW_9DOF), 25 bytes:**

```
NODE_ID      1   uint8
NODE_SEQ     2   uint16 LE   per-node sample counter (per-node loss detection)
TIMESTAMP_US 4   uint32 LE   node UWB-aligned timestamp, microseconds
AX AY AZ     6   int16 LE ×3 raw accelerometer counts
GX GY GZ     6   int16 LE ×3 raw gyroscope counts
MX MY MZ     6   int16 LE ×3 raw magnetometer counts (0 if MAG disabled)
```

**Node record — FORMAT 1 (SFLP_QUAT), 21 bytes:**

```
NODE_ID      1   uint8
NODE_SEQ     2   uint16 LE
TIMESTAMP_US 4   uint32 LE
QW QX QY QZ  8   int16 LE ×4 quaternion, Q15 fixed-point (×32767)
MX MY MZ     6   int16 LE ×3 raw magnetometer counts (0 if MAG disabled)
```

### 3.2 `MSG_RANGE`

```
FRAME_SEQ    2   uint16 LE
TIMESTAMP_US 4   uint32 LE   master time of the ranging round
PAIR_COUNT   1   uint8
records[]    var PAIR_COUNT × range record
```

**Range record, 4 bytes:** `NODE_A(1) NODE_B(1) DIST_MM(uint16 LE)` — distance in mm
(0–65.5 m range). Ranging runs at `RANGING_RATE_HZ` (25–50 Hz), slower than IMU.

## 4. Scale factors (counts → physical)

These depend on the full-scale ranges the firmware configures. **They must match
the firmware's config constants (`IMU_ACCEL_FS_G`, `IMU_GYRO_FS_DPS` — not yet
written) and the constants in `host/wearable_imu/ingest/protocol.py`.** v1 defaults:

| Quantity | Full scale | Sensitivity (LSB) | To physical |
|---|---|---|---|
| Accel | ±8 g | 0.244 mg/LSB | `g = raw × 0.244e-3`; `m/s² = g × 9.80665` |
| Gyro | ±2000 dps | 70 mdps/LSB | `dps = raw × 0.070`; `rad/s = dps × π/180` |
| Mag (BMM350) | not yet characterized | not yet characterized | pending mag bring-up — see [06](06-calibration.md) |

> Values are LSM6DSV-family datasheet figures — **verify against the LSM6DSV16B datasheet
> when hardware arrives.**

## 5. Sample rate note

The LSM6DSV16B ODR grid is `… 30, 60, 120, 240 …` Hz — **there is no 100 Hz step.** v1 runs
the sensor at **120 Hz** (closest to the README's 100 Hz target). Because every sample carries
a `TIMESTAMP_US` and the orientation filters integrate by `dt`, the exact nominal rate is not
load-bearing; the host can also decimate 120→100 Hz if a strict rate is ever required.

## 6. Bandwidth check

RAW_9DOF: envelope(8) + IMU header(4) + 25 B/node.
- 1 node @ 120 Hz: `(8+4+25) × 120 = 4.4 kB/s ≈ 35 kbps`
- 8 nodes aggregated @ 120 Hz: `(8+4+8×25) × 120 = 26.6 kB/s ≈ 213 kbps` — comfortable for one BLE 5.x link.

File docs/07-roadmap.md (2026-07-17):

# 07 — Roadmap & Open Items

## Build phases

| Phase | Milestone |
|---|---|
| 1 | Firmware + data path — node sampling, UWB TDMA, master aggregation, host ingest over SWD/SWO |
| 2 | Visualization — orientation → joint angles → DH → live 3D (synthetic data first) |
| 3 | BLE uplink — integrate after wired path is proven |
| 4 | EKF — Kalman filter fusing UWB inter-node distances for drift/position |

## Phase 1 progress

Done (host side — real, tested code):
- [x] Wire protocol spec ([03-communication.md](03-communication.md)) — authoritative.
- [x] Host codec + streaming parser with resync (`ingest/protocol.py`, 233 lines); tests + golden vector (`host/tests/test_protocol.py`).
- [x] Host ingest (`ingest/reader.py`): file replay + serial; `make_source` factory.
- [x] Synthetic source emitting real wire bytes (`sim/generator.py`); capture/replay via `main.py`.

Done (hardware/tooling):
- [x] CubeMX project generated for the STM32WB55CEUx (`firmware/Core/`, `Drivers/`, `Middlewares/`, `ThirdParty/`, `USB_Device/`, STM32CubeIDE project files). Replaces an earlier scaffolded `firmware/node/{App,Comms,Drivers,Sensors,Power}` stub layout (all TODO placeholders, no logic) — that layout was removed.
- [x] IMU + magnetometer bring-up smoke test: firmware reads both sensors and
      prints raw values over serial, viewed with a serial monitor app. No
      sampling pipeline, packet format, or buffering yet — this is a "sensors
      are alive and readable" check, not a data path. **Needs confirming:** this is
      very likely read over native USB-CDC (the MCU has native USB — see
      [02-hardware.md](02-hardware.md)), not SWO as earlier docs assumed;
      reconcile once confirmed.

Not started (correcting a previous "done" claim — these files never had real
implementations and the stub versions have since been deleted):
- [ ] **Firmware packet serializer** — no `packet.c` exists (never did); needs writing
      against the wire protocol spec, golden-vector-matched to the host decoder.
- [ ] **Port abstraction (I2C for sensors, SPI for DWM3000) + LSM6DSV16BXTR driver** —
      not implemented; the old `Drivers/lsm6dsv16b.c` was a stub (`TODO` bodies only).
      Bus/address confirmed by the bring-up smoke test: I2C1, `0x6B`.
- [ ] **Node sample→pack→emit path** — not implemented; the old
      `App/role_sensor.c` was a stub (`for (;;) {}` with TODO comments), now removed.

Next in Phase 1:
- [ ] Implement the three items above against the generated CubeMX `Core/`.
- [ ] SWO/ITM data output; host SWO ingest (SWV → bytes).
- [ ] UWB TDMA schedule + DWM3000 driver; master aggregation.
- [ ] RAM ring buffer for jitter/retransmit (no on-node flash IC — the fabricated
      v1.0 board doesn't populate one; RAM buffering is the only local insurance).

## Parallel workstream — 5-DOF arm (teleoperation + calibration rig)

A 5-DOF robotic arm mirroring human upper-limb kinematics, used both as a
teleoperation demo and as a calibration/validation reference for the IMU
pipeline. Kinematics code lives in [`simulation/scripts/`](../simulation/scripts/)
(not yet folded into `test-rig/`). Mechanical CAD for the rig itself has
started, under [`test-rig/hardware/mechanical/v1.0/`](../test-rig/hardware/mechanical/v1.0/README.md).

- [x] **Forward kinematics** — `shoulder_arm_fk.m`. DH-parameterized, MATLAB GUI
      with joint sliders, real-time 3D visualization, physiological joint-limit
      checking. Validated.
- [x] **Inverse kinematics — implemented, UNTRUSTED / not validated.** `shoulder_arm_ik.m`
      (675 lines): analytical solver using wrist-center decoupling (Pieper-style)
      for position (θ1, θ2, θ4) + orientation matching (θ3, θ5), enumerates up to
      4 candidate solutions (elbow-up/down × sign branches), filters by joint
      limits, ranks by geodesic orientation error. Design doc:
      [`simulation/scripts/ik_design.md`](../simulation/scripts/ik_design.md).
      **Do not rely on this for calibration/ground-truth work until it's validated
      against known FK solutions — treat every output as unverified for now.**
- [ ] **End-effector adapter** — no piece exists yet to mount a wearable IMU
      node at the rig's end effector (needed for both teleop and
      calibration/ground-truth use). Not designed.
- [ ] **Wearable IMU rig variant ("fork")** — a modified wearable IMU enclosure
      built to attach to the rig exists, but isn't in this repo yet; CAD needs
      to be added.
- [ ] **Reprint the `arm` piece** — the physical part currently on the lab rig
      needs a fresh print.

## Hardware revisions

- **v1.0 (current):** first bring-up board. See `hardware/electronics/CHANGELOG.md`.
  Known issue: the DWM3000 UWB antenna placement/keepout doesn't carefully follow
  Qorvo's layout guidelines (clearance, ground pour keepout, feed line length),
  which may affect range/link margin.
- **Decision pending v1.0 evaluation:** first see how well v1.0 actually performs
  (range, link margin, general bring-up) before committing to a fix path.
  - If v1.0 is good enough or only needs the antenna corrected: **v1.1**, a
    placement-only bug-fix spin, no other redesign.
  - If v1.0 falls short in ways that justify a bigger change: skip v1.1 and fold
    the antenna fix into **v2.0** (AoA UWB with custom PCB antennas) instead —
    no point doing two board spins if a larger redesign is coming anyway.

## Open items

- [ ] **Data format:** raw 9-DOF vs SFLP quaternion + raw mag. What this actually
      decides: whether each node transmits raw accel+gyro+mag counts (host does
      100% of the sensor fusion — maximum flexibility, ~40 B/sample) or the
      LSM6DSV16B's onboard SFLP quaternion + raw mag (device does the accel+gyro
      fusion itself, smaller/faster over the air, but less flexible if the fusion
      algorithm ever needs to change). Not yet decided.
- [x] **Magnetometer:** **using it for v1.** Firmware bring-up so far is a serial
      print smoke test only (see Phase 1 above) — no sampling pipeline or packet
      path yet.
- [x] **Battery capacity: 120 mAh.**
- [ ] **Node count for initial tests:** 2 confirmed (wrist, clavicle), chest possible
      as a 3rd → 6–8
- [x] **Sample rate:** **120 Hz** — the LSM6DSV16B ODR grid has no 100 Hz step; 120 Hz
      is the closest to the README target. Samples are timestamped so the exact rate is
      not load-bearing; host can decimate 120→100 if ever needed.
- [x] **BLE receiver: host-native.** The PC's own Bluetooth receives the uplink; no extra receiver hardware.
- [ ] **Orientation filter:** complementary vs Madgwick vs VQF vs SFLP. Not reached
      yet — the pipeline currently only exists as far as forward kinematics +
      visualization (the MATLAB arm GUI); no real orientation-filter work has
      started on either the arm or the wearable side.
- [ ] **EKF scope:** confirm phase-2 (not v1)
- [ ] **IK validation:** confirm `shoulder_arm_ik.m` against known FK solutions (see above)
- [ ] **v1.0 evaluation → v1.1 vs v2.0 decision:** bring up and test v1.0 (range,
      link margin), then decide whether the DWM3000 antenna issue gets a v1.1
      placement-only fix or gets folded into a v2.0 redesign (see "Hardware
      revisions" above)
- [ ] **Onboarding doc for new students** — not written yet. Needs to cover
      at least: STM32CubeProgrammer (flashing, updating the FUS / BLE stack),
      Serial Monitor Pro (viewing the sensor bring-up smoke-test output).
- [ ] **Battery connector:** currently JST-SH 1.0mm 2-pin (`JST_SH_SM02B-SRSS-TB`
      in the v1.0 schematic). Consider switching to **JST-XH 2.54mm 2-pin** for
      v1.1/v2.0 — the connector that ships on most off-the-shelf LiPo packs,
      avoiding re-terminating batteries by hand.
- [ ] **Mechanical BOMs missing:** no bill of materials exists yet for either the
      wearable case (`hardware/mechanical/v1.0/`) or the rig
      (`test-rig/hardware/mechanical/v1.0/`) — fasteners, standoffs, print
      material, and any off-the-shelf hardware (e.g. rig servos) aren't
      documented anywhere. Needs the actual parts list from whoever built them.
- [ ] **Mechanical fabrication process undocumented:** unlike the PCB (fabbed via
      JLCPCB — see `hardware/electronics/v1.0/README.md`), the 3D-printing
      process for the case and rig (printer/service, material, settings) isn't
      written down anywhere.
- [ ] **Tools list undocumented:** no written list of the tools used to build and
      assemble the hardware (wire stripper is the only one mentioned so far) —
      would help new students know what to have on hand.

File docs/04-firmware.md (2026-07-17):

# 04 — Firmware

> Node firmware for the STM32WB55CEUx. Expands README §7 (phase 1).

## Status

**Nothing described below is implemented yet.** Only the CubeMX-generated project
skeleton exists (`firmware/Core/`, `Drivers/`, `Middlewares/`, `ThirdParty/`,
`USB_Device/` — see `firmware/README.md`). An earlier scaffolded
`firmware/node/{App,Comms,Drivers,Sensors,Power}` layout, referenced by older
versions of this doc, was pure stub code (empty `TODO` function bodies) and has
been deleted. The architecture below is the **plan** for what gets built next,
not a status report — see [07-roadmap.md](07-roadmap.md) for what's actually done.

## Planned architecture

```
firmware/
├── Core/        # CubeMX-generated (do not edit by hand) — exists today
├── App/         # app_main, role_master, role_sensor — top-level state machines (planned)
├── Drivers/     # device drivers + the port abstraction (port.h) (planned)
├── Comms/       # packet serializer, uwb_tdma, ble_serial, swo_data (planned)
├── Sensors/     # imu, mag, fusion (glue: drivers -> raw counts -> packet) (planned)
└── Power/       # charger (BQ25185), fuel_gauge (MAX17048) (planned)
```

Note: today's real `Drivers/` (CMSIS + STM32WBxx HAL, CubeMX-generated) and the
planned app-layer `Drivers/` above will coexist — the app-layer one is thin
device drivers written against a port abstraction, not the HAL itself.

### Layering (why drivers shouldn't call the HAL directly)

The plan is to write drivers against a `port.h` (a tiny bus/timing abstraction),
**not** the STM32 HAL directly. This would let them compile and be reasoned about
independent of what peripheral/pins CubeMX assigns. Both buses are in play here:
the IMU and magnetometer are **I2C** (one shared bus, I2C1), while the DWM3000
UWB module is the only **SPI** device on the node (SPI1). `port.h` would wrap
`HAL_I2C_Mem_Read`/`HAL_I2C_Mem_Write` for the sensors, `HAL_SPI_TransmitReceive`
for the DWM3000, plus `HAL_Delay` and a 1 MHz `TIM` counter (`port_micros`) —
none of this exists yet.

## v1 sensor data path (planned)

Intended behavior: **sample IMU(+mag) → build one-node frame → emit**, bringing up
over **SWO (wired)** first, later swapped for UWB TDMA transmit in the node's
assigned slot. The node only ever handles **raw int16 counts** — all scaling/bias
is host-side (thin-node philosophy). None of this is written yet.

## Wire protocol

The format is specified in [03-communication.md](03-communication.md) — **that doc
is authoritative; change it before either implementation.** The host decoder
(`host/wearable_imu/ingest/protocol.py`) implements it today and is tested against
a golden vector (`host/tests/test_protocol.py`). The firmware serializer doesn't
exist yet; once written, it should reproduce the same golden vector so the two
encoders can't drift.

## Driver notes — LSM6DSV16BXTR (planned)

- **I2C1, address `0x6B`** (SDO pin pulled high on this board).
- v1 config: **±8 g, ±2000 dps, ODR 120 Hz** (no 100 Hz step exists — see §5 of the
  comms doc). FS settings must match the host scale constants.
- The bring-up smoke test (see [07-roadmap.md](07-roadmap.md)) already talks to this
  sensor at `0x6B` and reads a plausible WHO_AM_I — the address/bus are confirmed
  working; only the sampling/packing pipeline is unwritten.

## Driver notes — BMM350 (planned)

- **I2C1, address `0x14`** (ADSEL pin pulled low on this board) — same bus as the IMU.
- Full-scale / sensitivity: not yet characterized, pending mag bring-up (see
  [03-communication.md](03-communication.md) and [06-calibration.md](06-calibration.md)).
- Vendor driver lives in `firmware/ThirdParty/BMM350/`.

## Bring-up order

1. ~~Generate `Core/` from STM32CubeMX for the STM32WB55CEUx~~ — done. Implement `port.c`.
2. SWD/SWO wired link: verify IMU sampling + frames out via SWO.
3. UWB TDMA (data + sync + ranging).
4. BLE serial-over-BLE uplink.

## TDMA frame (planned — not implemented)

Nothing below is implemented or tested yet. These are pre-hardware-test design
estimates, not decisions — UWB hasn't been brought up at all (see
[07-roadmap.md](07-roadmap.md)), so treat every number here as provisional
until it's actually run on the DWM3000.

- One channel is intended to carry **data slots + ranging rounds + sync** via a
  single TDMA frame.
- Ranging is slow relative to data: **25–50 Hz** is expected to be plenty.
- All-pairs ranging scales as N(N-1)/2 (15 pairs @ 6 nodes, 28 @ 8 nodes). For
  upper-limb joint angles, **adjacent-segment pairs** may suffice — full mesh
  is probably not required, but this hasn't been tested.
- **Sync plan:** the master is intended to be the UWB time reference, with
  nodes sub-ns aligned **on the body, before** data leaves; the master
  timestamps aggregated data.

TODO: define exact frame length, slot assignments, sync beacon timing — none
of this is decided, only sketched above.

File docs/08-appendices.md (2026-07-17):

# 08 — Appendices

## References

- **[Ultra Inertial Poser (UIP)](https://siplab.org/projects/UltraInertialPoser)** —
  SIGGRAPH 2024 ([ACM DL](https://dl.acm.org/doi/10.1145/3641519.3657465),
  [arXiv](https://arxiv.org/abs/2404.19541),
  [code](https://github.com/eth-siplab/UltraInertialPoser)). Sparse body-worn IMU + UWB
  ranging, fused on host with VQF, per-pair EKF, LSTM + graph-conv network, physics
  optimizer. Direct inspiration for sensing approach and "thin nodes, heavy host" philosophy.

## Glossary

| Term | Meaning |
|---|---|
| DH | Denavit-Hartenberg — systematic parameterisation of rigid-body kinematic chains |
| SFLP | Sensor Fusion Low Power — onboard quaternion output of LSM6DSV16B |
| TDMA | Time Division Multiple Access — UWB slot schedule |
| VQF | Versatile Quaternion-based Filter (Laidig & Seel, 2022) |
| SWO | Serial Wire Output — one-way MCU → host data channel through ST-LINK |
| NUS | Nordic UART Service — BLE serial-over-GATT convention |

## Data-sheet / resource links

- STM32WB55CE: https://www.st.com/en/microcontrollers-microprocessors/stm32wb55ce.html
- LSM6DSV16B: https://www.st.com/en/mems-and-sensors/lsm6dsv16b.html
- BMM350: https://www.bosch-sensortec.com/products/motion-sensors/magnetometers/bmm350/
- DWM3000: https://www.qorvo.com/products/p/DWM3000
- BQ25185: https://www.ti.com/product/BQ25185
- MAX17048: https://www.analog.com/en/products/max17048.html

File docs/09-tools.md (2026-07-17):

# 09 — Tools

> **Not yet complete** — a starting point to expand as the actual build tools
> get listed out.

## Electronics assembly / rework

| Tool | Used for | Notes |
|---|---|---|
| *(TODO)* | Soldering / rework | Model not documented |
| *(TODO)* | Programming/flashing | See STM32CubeProgrammer note in [07-roadmap.md](07-roadmap.md) (onboarding doc item) |

## Mechanical / 3D printing

| Tool | Used for | Notes |
|---|---|---|
| *(TODO)* | Printing the case / rig parts | Printer or print service not documented — see [02-hardware.md](02-hardware.md) and the case/rig READMEs |

## Software

| Tool | Used for | Notes |
|---|---|---|
| STM32CubeIDE | Firmware development, flashing | |
| STM32CubeProgrammer | Flashing, FUS/BLE stack update | Usage not yet documented — onboarding doc TODO |
| KiCad (+ fabrication-toolkit plugin) | PCB schematic/layout, JLCPCB export | See [`hardware/electronics/v1.0/README.md`](../hardware/electronics/v1.0/README.md#fabrication) |
| Fusion 360 | Rig mechanical CAD (`RIG.f3z`) | |
| Serial Monitor Pro | Viewing sensor bring-up smoke-test output | See [07-roadmap.md](07-roadmap.md) |

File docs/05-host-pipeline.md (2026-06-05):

# 05 — Host Pipeline

> Expand on README §6.

## Stages

| # | Module | Input | Output |
|---|---|---|---|
| 0 | calibration | T/N-pose capture | sensor-to-segment alignment matrices |
| 1 | orientation | accel + gyro (+ mag) | world-frame quaternion per segment |
| 2 | kinematics | adjacent quaternion pairs | joint angles |
| 3 | EKF *(phase 2)* | joint angles + UWB ranges | drift-corrected angles + positions |
| 4 | forward kinematics | joint angles + segment lengths | 3D joint positions |
| 5 | viz | 3D joint positions | live rendered skeleton |

## v1 path

Stages 0 → 1 → 2 → 4 → 5. No EKF needed for a working visualization.

## Orientation filter options

- **Complementary filter** — simplest, good starting point.
- **Madgwick** — well-documented, single tuning parameter (β).
- **VQF** — used by UIP (SIGGRAPH 2024 reference); handles magnetic disturbances well.
- **SFLP** — onboard LSM6DSV16B output; offloads host compute.

Decision open — see [open items](07-roadmap.md).

## Denavit-Hartenberg (DH) forward kinematics

TODO: define DH parameter table for the upper-limb model (shoulder → elbow → wrist).

## Synthetic data

`host/wearable_imu/sim/` generates synthetic IMU streams for pipeline development
before hardware is ready.

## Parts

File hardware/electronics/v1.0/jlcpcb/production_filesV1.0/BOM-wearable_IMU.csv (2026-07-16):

Comment | Designator | Footprint | LCSC | Quantity
0p3 | C23 | C_0402_1005Metric | C76909 | 1
0p8 | C20 | C_0402_1005Metric | C3859264 | 1
100k | R15,R6 | R_0402_1005Metric | C25741 | 2
100n | C10,C11,C13,C14,C16,C17,C19,C22,C25,C27,C28,C5,C7,C8 | C_0402_1005Metric | C307331 | 14
10k | R5,R7,R8,R9 | R_0402_1005Metric | C25744 | 4
10n | L1,L5 | L_0402_1005Metric | C77103 | 2
10p | C18,C21 | C_0402_1005Metric | C32949 | 2
10u | L2 | L_0805_2012Metric | C162582 | 1
10u | C3,C30,C4,C9 | C_0603_1608Metric | C96446 | 4
18k | R3 | R_0402_1005Metric | C138044 | 1
1k | R12,R14,R4 | R_0402_1005Metric | C11702 | 3
1u | C1,C2 | C_0402_1005Metric | C52923 | 2
2n7 | L3 | L_0402_1005Metric | C113054 | 1
2u2 | C6 | C_0402_1005Metric | C77002 | 1
32MHz | X2 | Crystal_SMD_2016-4Pin_2.0x1.6mm | C1986260 | 1
32kHz768 | X1 | Crystal_SMD_2012-2Pin_2.0x1.2mm | C891748 | 1
4u7 | C12,C24,C29 | C_0603_1608Metric | C19666 | 3
5k1 | R1,R10,R11,R13,R2 | R_0402_1005Metric | C25905 | 5
8n3 | L4 | L_0402_1005Metric | C412363 | 1
AMCA31-2R450G-S1F-T3 | AE1 | XDCR_AMCA31-2R450G-S1F-T3 | C3283994 | 1
BMM350 | U5 | DP_WLCSP-9_1.21x1.22mm_Layout3x3_P0.4mm | C17225907 | 1
BQ25185DLHR | U2 | WSON10_DLH_TEX | C19725033 | 1
DLF162500LT-5028A1 | FLT1 | FILTER-SMD_0603-4P-L1.6-W0.8-L-1 | C531364 | 1
DP_USB_C_Receptacle_USB2.0_16P | J1 | DP_USB_C_Receptacle_GCT_USB4105-xx-A_16P_TopMnt_Horizontal | C393939 | 1
LED_R | D1 | LED_0402_1005Metric | C25503345 | 1
LED_V | D2,D3 | LED_0402_1005Metric | C965793 | 2
LSM6DSV16BXTR | U6 | LGA-14_3x2.5mm_P0.5mm_LayoutBorder3x4y | C5267394 | 1
MAX17048G_T10 | U4 | DFN-8-1EP_2x2mm_P0.5mm_EP0.9x1.3mm | C2682616 | 1
STM32WB55CEUx | U7 | QFN-48-1EP_7x7mm_P0.5mm_EP5.6x5.6mm | C911135 | 1
SW_SPDT | SW1 | SW-SMD_MST-12D18G4-SPDT-SLIDE-SWITCH | C49023767 | 1
TLV74218PDQNR | U8 | X2SON-4_L1.0-W1.0-P0.65-BL-EP | C485140 | 1
TPSM828224SILR | U3 | USIP-10_L2.5-W2.0-P0.50-BL | C2862913 | 1
USBLC6-2P6 | U1 | SOT-666 | C15999 | 1

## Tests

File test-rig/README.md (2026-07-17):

# test-rig/

Self-contained sub-project: a motorised 5-DOF arm rig serving **two purposes** —
(1) a teleoperation demo, driven live from the wearable IMU nodes, and (2) a
calibration/ground-truth reference, moved through known joint angles to validate
the IMU pose estimation pipeline against a known reference.

**Status: mostly not started.** Mechanical design of the rig arm is underway
(see `hardware/mechanical/v1.0/`); firmware, control software, and the servo
driver PCB don't exist yet. The empty placeholder folders that used to sit
under this one (`control/`, `firmware/`, `hardware/electronics/v1.0/`) were
removed to keep the repo tree honest — they held nothing but stubs. They'll be
recreated once work actually starts on each part.

## Purpose

**Teleoperation:**
1. Read live wearable IMU node data.
2. Drive the rig's joints to mirror the estimated human arm pose in real time.

**Calibration / ground truth:**
1. Drive the rig through known joint angles.
2. Simultaneously record IMU node data.
3. Compare estimated angles to ground truth to quantify filter error.

## Structure

| Folder | Status | Contents |
|---|---|---|
| [`hardware/mechanical/v1.0/`](hardware/mechanical/v1.0/README.md) | **In progress** | Rig 3D files (arm links, servo mounts) — Fusion 360 source + isometric render. |
| `hardware/electronics/v1.0/` | Planned, not created | Rig servo driver / controller PCB. MCU + servo driver choice not yet decided. |
| `firmware/` | Planned, not created | Rig motion controller firmware. Git-versioned, no version folders — tag releases as `rig-vX.Y.Z`. |
| `control/` | Planned, not created | Host-side: drive the rig through scripted motions, log ground-truth joint angles (timestamped CSV), and compare against the IMU pipeline's estimated angles (error plot). |

Follows the same versioning convention as the main project: hardware gets
version folders, firmware/control are git-tagged (`rig-vX.Y.Z`, separate from
the main system's `imu-vX.Y.Z`).

## Known gaps

See [`hardware/mechanical/v1.0/README.md`](hardware/mechanical/v1.0/README.md#known-gaps):
missing end-effector adapter to mount a wearable IMU node on the rig, a
modified/"fork" wearable IMU rig variant that exists but isn't in this repo
yet, and the lab's `arm` piece needing a reprint.

## Related work

The 5-DOF arm forward/inverse kinematics — used both as a teleoperation demo
and as this rig's calibration/validation reference — currently lives in
[`simulation/scripts/`](../simulation/scripts/) (`shoulder_arm_fk.m`,
`shoulder_arm_ik.m`), not yet inside this sub-project's structure. FK is
implemented and validated; IK is implemented (`shoulder_arm_ik.m`,
analytical 5-DOF solver) but not yet validated against known solutions.

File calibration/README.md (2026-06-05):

# calibration/

Calibration routines and saved calibration profiles.

## Saved profiles

Profiles are stored as JSON: `<subject>_<date>.json`

```json
{
  "subject": "subject_01",
  "date": "2026-01-01",
  "nodes": {
    "0": { "R_sensor_to_segment": [[...], [...], [...]], "accel_bias": [...], "gyro_bias": [...] },
    "1": { ... }
  },
  "mag_calibration": { "hard_iron": [...], "soft_iron": [[...], [...], [...]] }
}
```

## Procedure

See [docs/06-calibration.md](../docs/06-calibration.md) for the full T/N-pose procedure.
Run `tools/calibrate.py` to execute interactively.

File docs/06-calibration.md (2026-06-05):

# 06 — Calibration

> Sensor-to-segment alignment and saved calibration profiles.

## T-pose / N-pose procedure

TODO: define exact pose, duration, acceptance criteria.

## Outputs

- Per-node rotation matrix aligning sensor frame to segment frame.
- Saved to `calibration/<session_id>.json`.

## Magnetometer calibration

- Ellipsoid fitting for hard/soft iron correction.
- Required only if magnetometer is used (open item).

## Accelerometer / gyroscope

- Static bias estimation during the calibration pose.
- Gyro bias re-estimated at every power-on (device still for first N samples).

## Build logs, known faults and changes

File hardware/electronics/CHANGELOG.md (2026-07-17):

# Electronics CHANGELOG

## v1.1 — decision pending v1.0 evaluation

- Known issue: DWM3000 UWB antenna placement/clearance/keepout doesn't fully
  follow Qorvo's layout guidelines, which may affect range/link margin.
- Not yet decided whether this becomes a v1.1 placement-only fix or gets folded
  into a v2.0 redesign (AoA UWB + custom PCB antennas) instead — depends on how
  well v1.0 performs in bring-up. See `docs/07-roadmap.md`.

## v1.0 — initial bring-up revision

- First layout. STM32WB55CEUx + DWM3000 + LSM6DSV16B + BMM350. No on-node flash IC
  (confirmed against the fabricated BOM — not populated).
- USB-C charges via BQ25185, and also carries native USB data (the STM32WB55CEUx has
  native USB — corrects an earlier "charging only, no MCU USB" claim made when the MCU
  was mistakenly assumed to be a STM32WBA55).
- TC2030-IDC footprint (Tag-Connect) for debug/data — bare pogo-pin pads on the PCB, no
  soldered connector; mates with a separate TC2030 cable/clip.

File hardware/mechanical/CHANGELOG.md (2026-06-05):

# Mechanical CHANGELOG

## v1.0 — initial case

- First enclosure design for node v1.0 PCB.

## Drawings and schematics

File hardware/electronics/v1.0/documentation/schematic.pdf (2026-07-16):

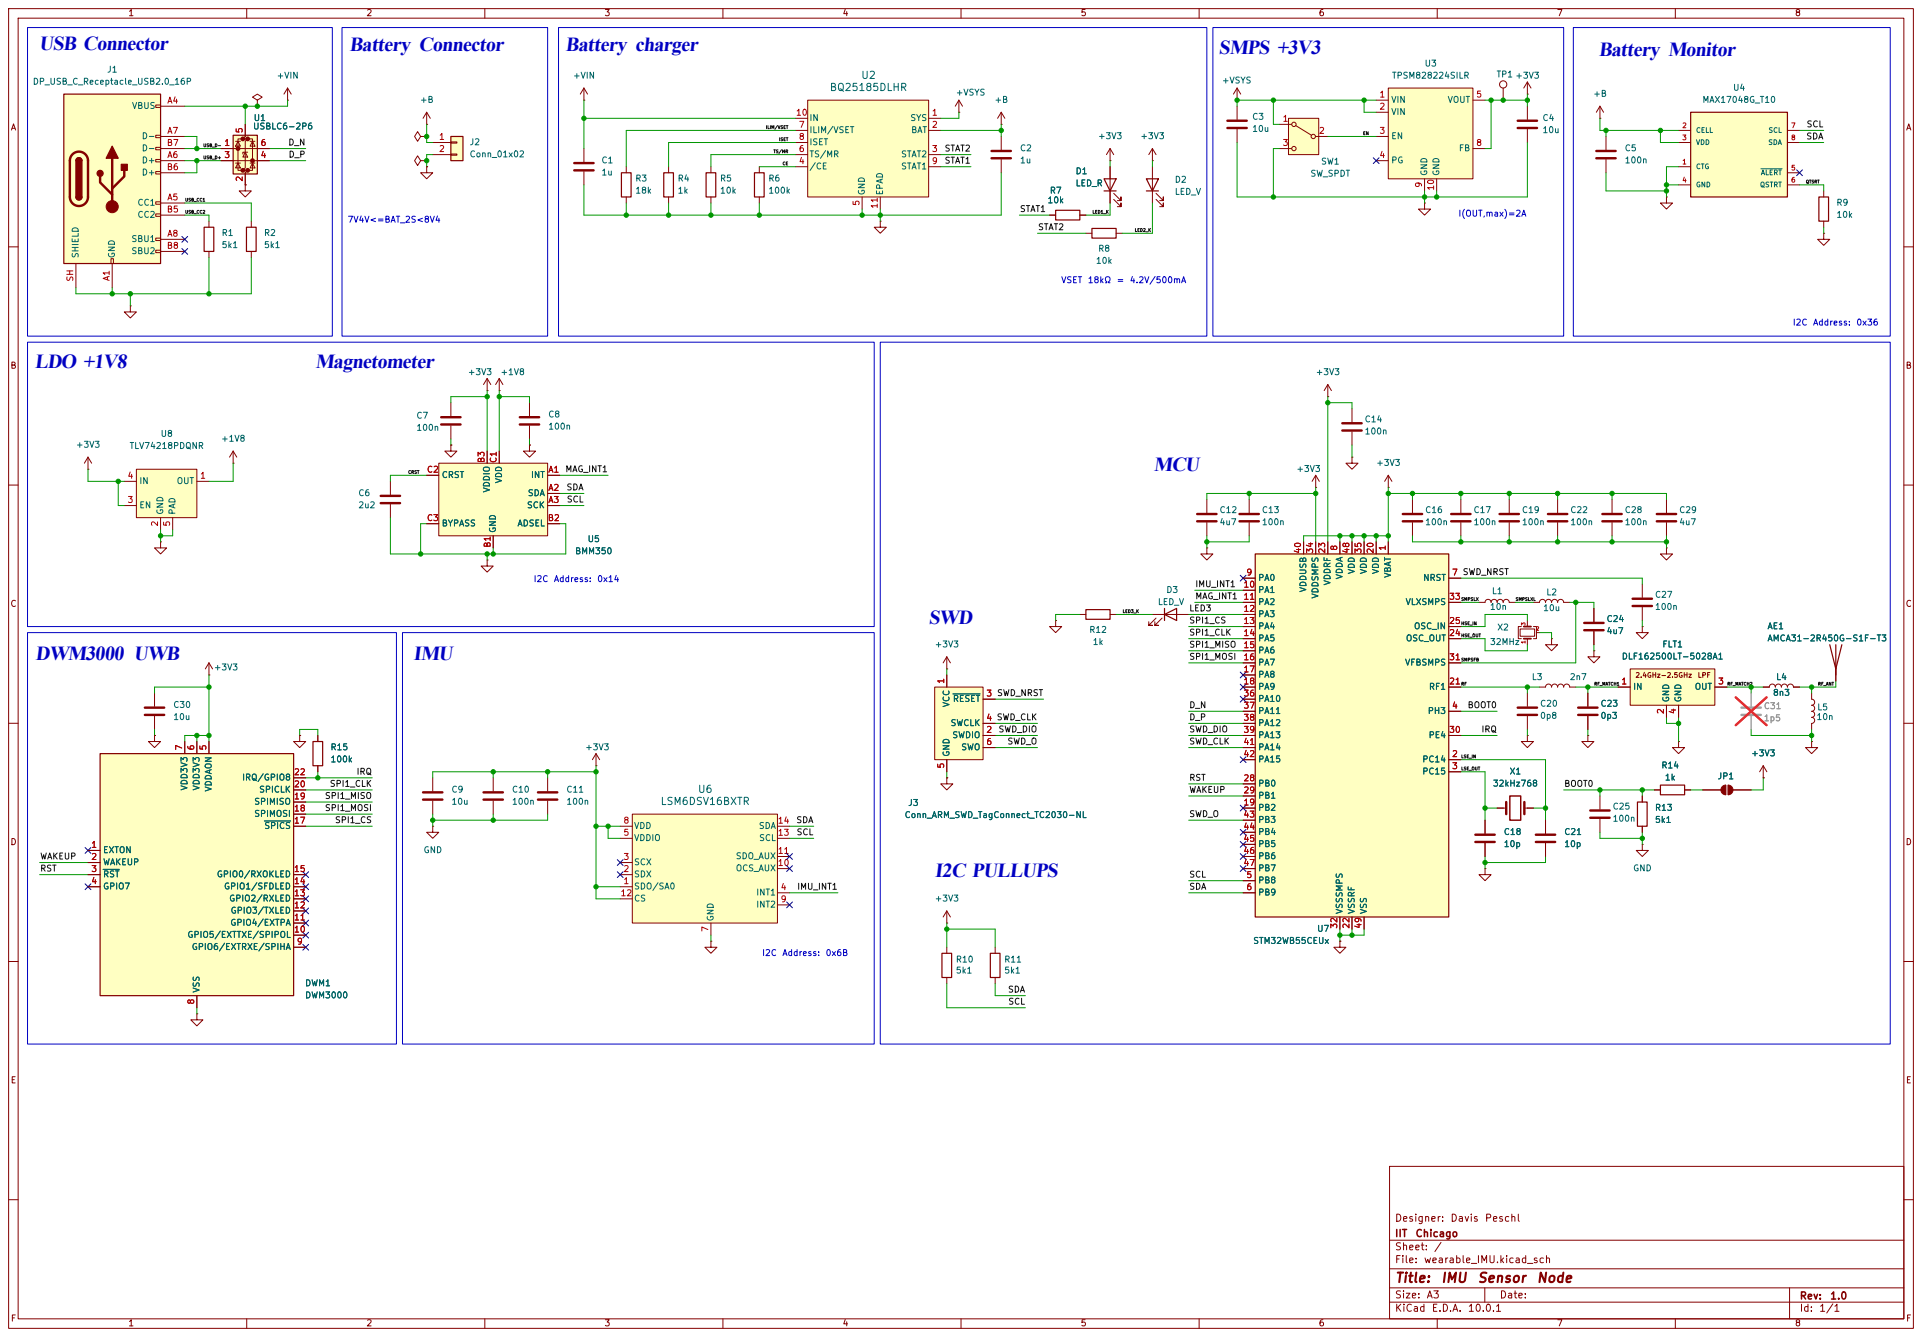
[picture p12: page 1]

tolerancia de la resistencias SWD
I2C Address: 0x14 Battery charger

8 GPIO6/EXTRXE/SPIHA 9 GPIO5/EXTTXE/SPIPOL 10 GPIO4/EXTPA 11 GPIO3/TXLED 12 GPIO2/RXLED 13 GPIO1/SFDLED 14 GPIO0/RXOKLED 15

Designer: Davis Peschl
IIT Chicago
Sheet: /
File: wearable_IMU.kicad_sch
Title: IMU Sensor Node

Size: A3 | Rev: 1.0 | F Date:
KiCad E.D.A. 10.0.1 | Id: 1/1

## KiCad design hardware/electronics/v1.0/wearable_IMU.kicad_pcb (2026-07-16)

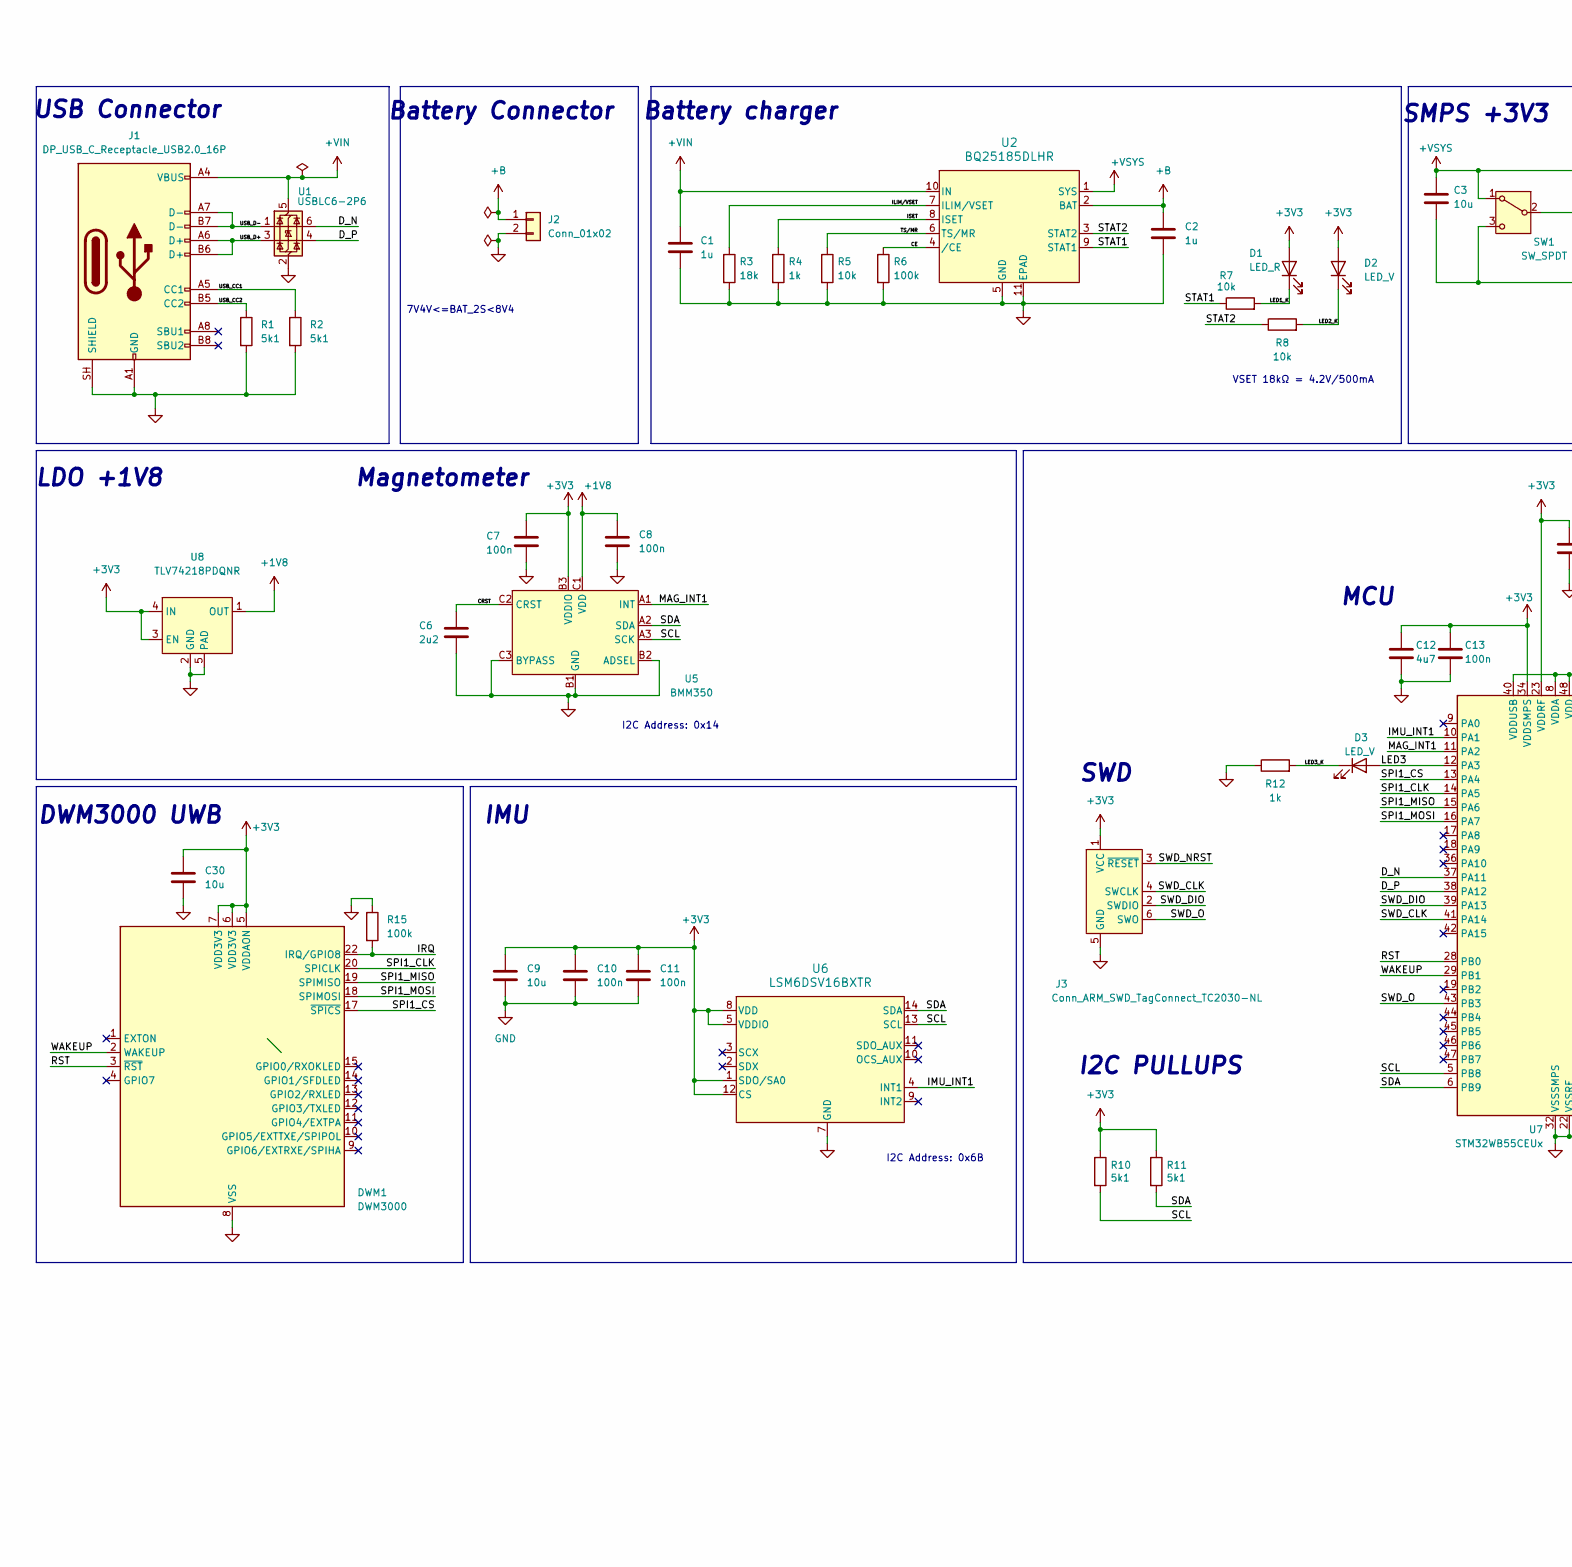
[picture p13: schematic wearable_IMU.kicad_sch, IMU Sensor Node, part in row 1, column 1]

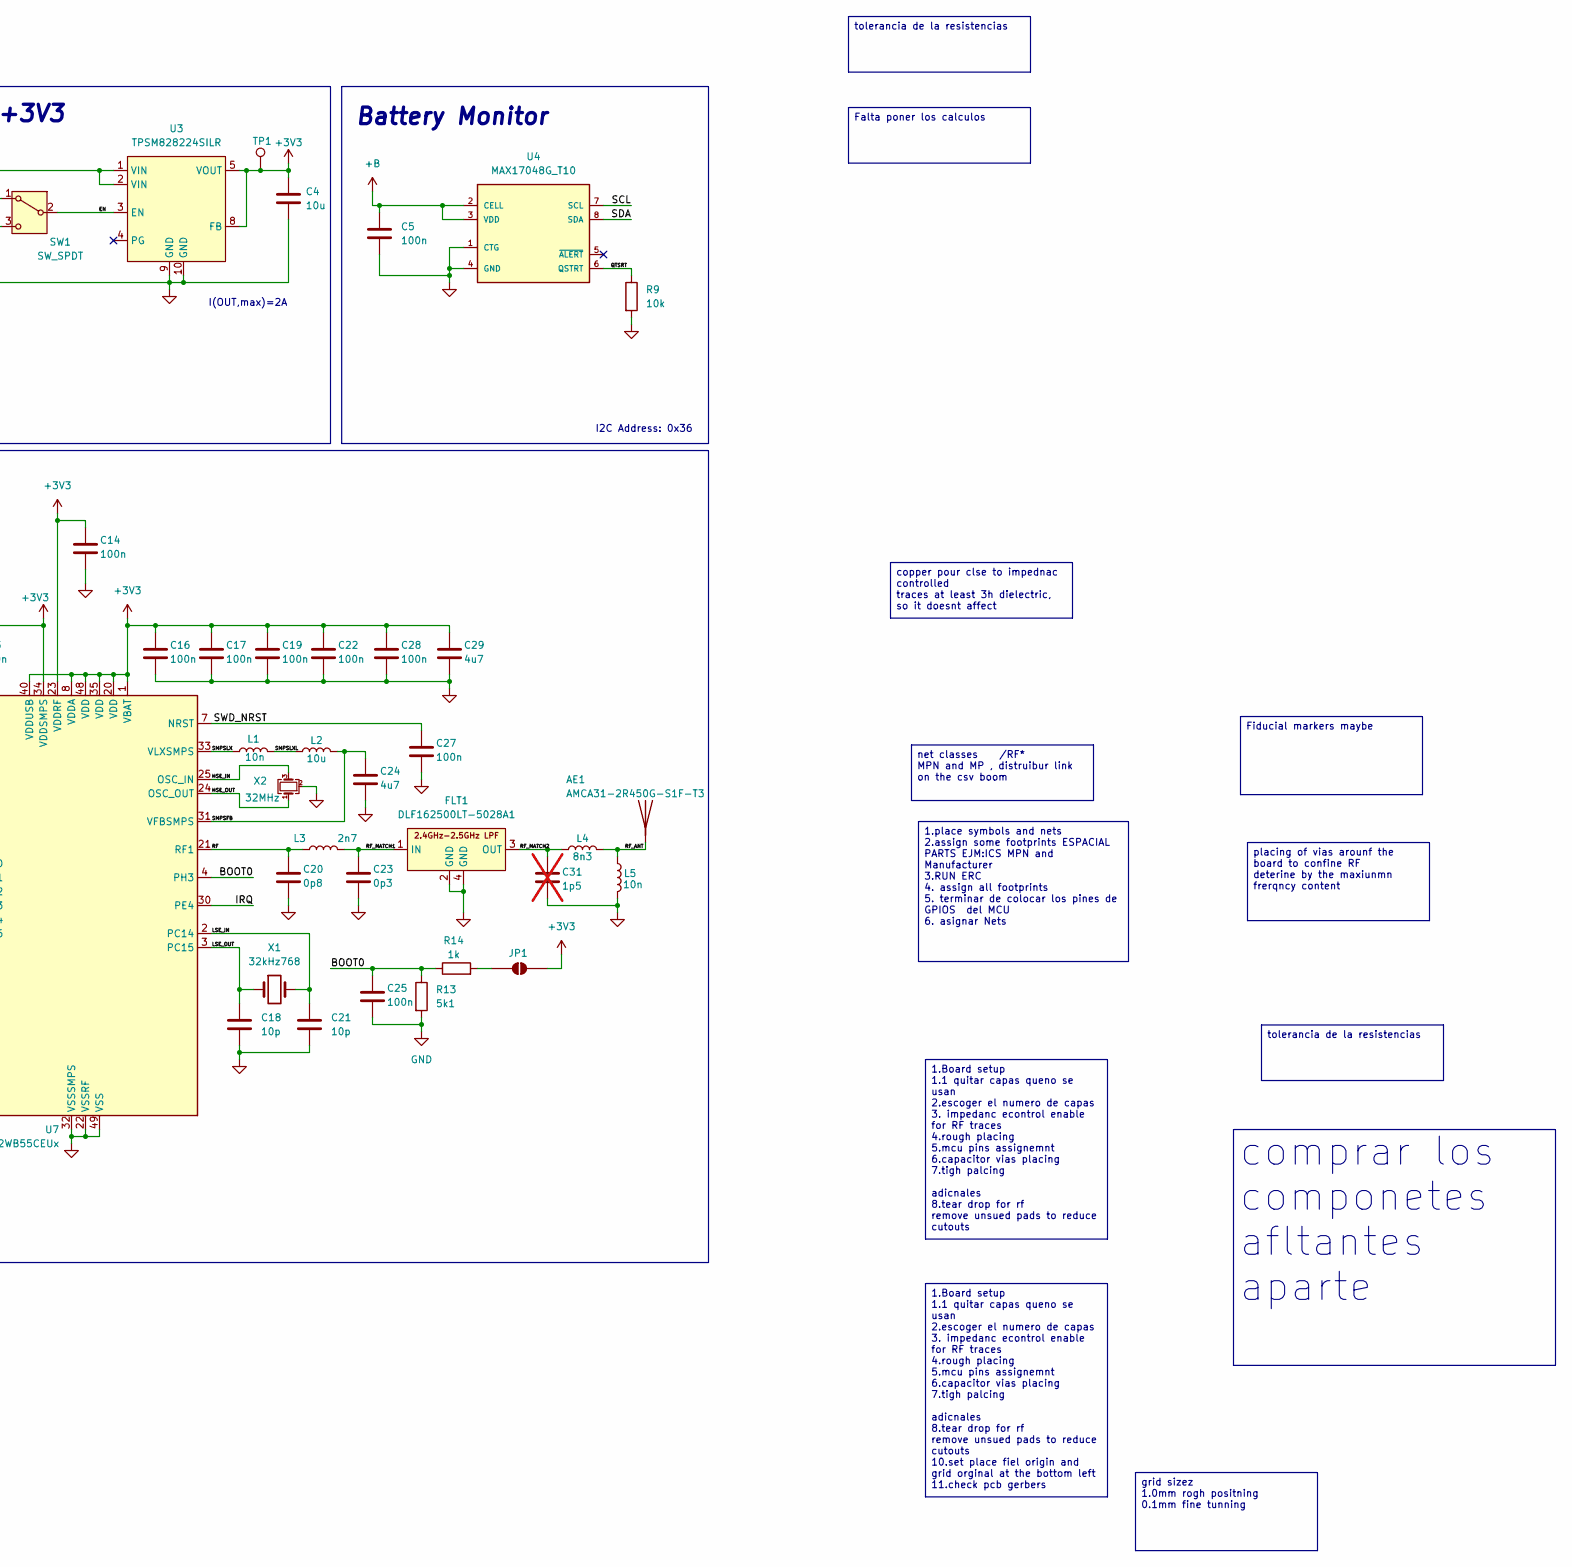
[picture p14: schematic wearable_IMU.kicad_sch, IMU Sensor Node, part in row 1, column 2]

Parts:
AE1: AMCA31-2R450G-S1F-T3; XDCR_AMCA31-2R450G-S1F-T3; MPN AMCA31-2R450G-S1F-T3
C1, C2: 1u; C_0402_1005Metric
C3, C4, C9, C30: 10u; C_0603_1608Metric
C5, C7, C8, C10, C11, C13, C14, C16, C17, C19, C22, C25, C27, C28: 100n; C_0402_1005Metric
C6: 2u2; C_0402_1005Metric; MPN 0805YC225KAT2A
C12, C29: 4u7; C_0603_1608Metric
C18, C21: 10p; C_0402_1005Metric
C20: 0p8; C_0402_1005Metric; MPN GRM1555C1HR80BA01D
C23: 0p3; C_0402_1005Metric; MPN GRM1555C1HR30WA01D
C24: 4u7; C_0603_1608Metric; MPN GRM155R60J475KE19
C31: 1p5; C_0402_1005Metric; not fitted
D1: LED_R; LED_0402_1005Metric
D2, D3: LED_V; LED_0402_1005Metric
DWM1: DWM3000; MPN DWM3000TR13
FLT1: DLF162500LT-5028A1; FILTER-SMD_0603-4P-L1.6-W0.8-L-1; MPN DLF162500LT-5028A1; LCSC Part C531364
J1: DP_USB_C_Receptacle_USB2.0_16P; DP_USB_C_Receptacle_GCT_USB4105-xx-A_16P_TopMnt_Horizontal
J2: Conn_01x02; JST_SH_SM02B-SRSS-TB_1x02-1MP_P1.00mm_Horizontal
J3: Conn_ARM_SWD_TagConnect_TC2030-NL; Tag-Connect_TC2030-IDC-NL_2x03_P1.27mm_Vertical
JP1: SolderJumper_2_Open; SolderJumper-2_P1.3mm_Open_RoundedPad1.0x1.5mm
L1: 10n; L_0402_1005Metric; LCSC Part C445746
L2: 10u; L_0805_2012Metric; MPN LQM21FN100M70L; LCSC Part C162582
L3: 2n7; L_0402_1005Metric; LCSC Part C113054
L4: 8n3; L_0402_1005Metric; MPN LQW15AN8N3C10D; LCSC Part C412363
L5: 10n; L_0402_1005Metric; MPN LQW15AN9N7G00D; LCSC Part C269828
R1, R2, R10, R11, R13: 5k1; R_0402_1005Metric
R3: 18k; R_0402_1005Metric
R4, R12, R14: 1k; R_0402_1005Metric
R5, R7, R8, R9: 10k; R_0402_1005Metric
R6, R15: 100k; R_0402_1005Metric
SW1: SW_SPDT; SW-SMD_MST-12D18G4-SPDT-SLIDE-SWITCH
TP1: TestPoint; TestPoint_Pad_D1.5mm
U1: USBLC6-2P6; SOT-666
U2: BQ25185DLHR; WSON10_DLH_TEX; MPN BQ25185DLHR; DigiKey_Part_Number 296-BQ25185DLHRCT-ND
U3: TPSM828224SILR; USIP-10_L2.5-W2.0-P0.50-BL; MPN TPSM828224SILR; LCSC Part C2862913
U4: MAX17048G_T10; DFN-8-1EP_2x2mm_P0.5mm_EP0.9x1.3mm; MPN IC BATT MON LI-ION 1CELL 8TDFN; LCSC Part C2682616
U5: BMM350; DP_WLCSP-9_1.21x1.22mm_Layout3x3_P0.4mm; MPN BMM350; LCSC Part C17225907
U6: LSM6DSV16BXTR; LGA-14_3x2.5mm_P0.5mm_LayoutBorder3x4y; MPN LSM6DSV16BXTR
U7: STM32WB55CEUx; QFN-48-1EP_7x7mm_P0.5mm_EP5.6x5.6mm; MPN STM32WB55CEU6
U8: TLV74218PDQNR; X2SON-4_L1.0-W1.0-P0.65-BL-EP; MPN TLV74218PDQNR; LCSC Part C485140
X1: 32kHz768; Crystal_SMD_2012-2Pin_2.0x1.2mm; MPN NX2016_32M; LCSC Part C891748
X2: 32MHz; Crystal_SMD_2016-4Pin_2.0x1.6mm; MPN NX2016SA-32M-EXS00A-CS06465; LCSC Part C1986260

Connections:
+1V8: C8.1, U5.C1 (VDD), U8.1 (OUT)
+3V3: C4.1, C7.1, C9.1, C10.1, C11.1, C12.1, C13.1, C14.1, C16.1, C17.1, C19.1, C22.1, C28.1, C29.1, C30.1, D1.2 (A), D2.2 (A), DWM1.5 (VDDAON), DWM1.6 (VDD3V3), DWM1.7 (VDD3V3), J3.1 (VCC), JP1.2 (B), R10.1, R11.1, TP1.1 (1_1), U3.5 (VOUT), U3.6 (VOUT), U3.7 (VOUT), U3.8 (FB), U5.B3 (VDDIO), U6.1 (SDO/SA0), U6.5 (VDDIO), U6.8 (VDD), U6.12 (CS), U7.1 (VBAT), U7.8 (VDDA), U7.20 (VDD), U7.23 (VDDRF), U7.34 (VDDSMPS), U7.35 (VDD), U7.40 (VDDUSB), U7.48 (VDD), U8.3 (EN), U8.4 (IN)
+B: C2.1, C5.1, J2.1, U2.2 (BAT), U4.2 (CELL), U4.3 (VDD)
+VIN: C1.1, J1.A4 (VBUS), J1.A9 (VBUS), J1.B4 (VBUS), J1.B9 (VBUS), U1.5 (VBUS), U2.10 (IN)
+VSYS: C3.1, SW1.1 (A), U2.1 (SYS), U3.1 (VIN), U3.2 (VIN)
/BOOT0: C25.1, R13.1, R14.1, U7.4 (PH3)
/CE: R6.1, U2.4 (/CE)
/CRST: C6.1, U5.C2 (CRST)
/D_N: U1.6 (I/O1), U7.37 (PA11)
/D_P: U1.4 (I/O2), U7.38 (PA12)
/EN: SW1.2 (B), U3.3 (EN)
/HSE_IN: U7.25 (OSC_IN), X2.3
/HSE_OUT: U7.24 (OSC_OUT), X2.1
/ILIM/VSET: R3.1, U2.7 (ILIM/VSET)
/IMU_INT1: U6.4 (INT1), U7.10 (PA1)
/IRQ: DWM1.22 (IRQ/GPIO8), R15.2, U7.30 (PE4)
/ISET: R4.1, U2.8 (ISET)
/LED1_K: D1.1 (K), R7.2
/LED2_K: D2.1 (K), R8.2
/LED3: D3.2 (A), U7.12 (PA3)
/LED3_K: D3.1 (K), R12.2
/LSE_IN: C21.1, U7.2 (PC14), X1.2
/LSE_OUT: C18.1, U7.3 (PC15), X1.1
/MAG_INT1: U5.A1 (INT), U7.11 (PA2)
/QTSRT: R9.1, U4.6 (QSTRT)
/RF: C20.1, L3.1, U7.21 (RF1)
/RF_ANT: AE1.1 (A_1), L4.2, L5.1
/RF_MATCH1: C23.1, FLT1.1 (IN), L3.2
/RF_MATCH2: C31.1, FLT1.3 (OUT), L4.1
/RST: DWM1.3 (~RST), U7.28 (PB0)
/SCL: R10.2, U4.7 (SCL), U5.A3 (SCK), U6.13 (SCL), U7.5 (PB8)
/SDA: R11.2, U4.8 (SDA), U5.A2 (SDA), U6.14 (SDA), U7.6 (PB9)
/SMPSFB: C24.1, L2.2, U7.31 (VFBSMPS)
/SMPSLX: L1.1, U7.33 (VLXSMPS)
/SMPSLXL: L1.2, L2.1
/SPI1_CLK: DWM1.20 (SPICLK), U7.14 (PA5)
/SPI1_CS: DWM1.17 (~SPICS), U7.13 (PA4)
/SPI1_MISO: DWM1.19 (SPIMISO), U7.15 (PA6)
/SPI1_MOSI: DWM1.18 (SPIMOSI), U7.16 (PA7)
/STAT1: R7.1, U2.9 (STAT1)
/STAT2: R8.1, U2.3 (STAT2)
/SWD_CLK: J3.4 (SWCLK), U7.41 (PA14)
/SWD_DIO: J3.2 (SWDIO), U7.39 (PA13)
/SWD_NRST: C27.1, J3.3 (~RESET), U7.7 (NRST)
/SWD_O: J3.6 (SWO), U7.43 (PB3)
/TS/MR: R5.1, U2.6 (TS/MR)
/USB_CC1: J1.A5 (CC1), R2.1
/USB_CC2: J1.B5 (CC2), R1.1
/USB_D+: J1.A6 (D+), J1.B6 (D+), U1.3 (I/O2)
/USB_D-: J1.A7 (D-), J1.B7 (D-), U1.1 (I/O1)
/WAKEUP: DWM1.2 (WAKEUP), U7.29 (PB1)
GND: C1.2, C2.2, C3.2, C4.2, C5.2, C6.2, C7.2, C8.2, C9.2, C10.2, C11.2, C12.2, C13.2, C14.2, C16.2, C17.2, C18.2, C19.2, C20.2, C21.2, C22.2, C23.2, C24.2, C25.2, C27.2, C28.2, C29.2, C30.2, C31.2, DWM1.8 (VSS), DWM1.16 (VSS), DWM1.21 (VSS), DWM1.23 (VSS), DWM1.24 (VSS), FLT1.2 (GND), FLT1.4 (GND), J1.A1 (GND), J1.A12 (GND), J1.B1 (GND), J1.B12 (GND), J1.SH (SHIELD), J2.2, J3.5 (GND), L5.2, R1.2, R2.2, R3.2, R4.2, R5.2, R6.2, R9.2, R12.1, R13.2, R15.1, SW1.3 (C), U1.2 (GND), U2.5 (GND), U2.11 (EPAD), U3.9 (GND), U3.10 (GND), U4.1 (CTG), U4.4 (GND), U4.9 (EP), U5.B1 (GND), U5.B2 (ADSEL), U5.C3 (BYPASS), U6.6 (GND), U6.7 (GND), U7.22 (VSSRF), U7.32 (VSSSMPS), U7.49 (VSS), U8.2 (GND), U8.5 (PAD), X2.2 (G), X2.4 (G)
unnamed: JP1.1 (A), R14.2

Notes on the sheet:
I2C Address: 0x14
MCU
I2C Address: 0x6B
I2C PULLUPS
VSET 18kΩ = 4.2V/500mA
SWD
IMU
Battery charger
7V4V<=BAT_2S<8V4
Battery Monitor
SMPS +3V3
I(OUT,max)=2A
Magnetometer
LDO +1V8
USB Connector
DWM3000 UWB
Battery Connector
I2C Address: 0x36
1.Board setup 1.1 quitar capas queno se usan 2.escoger el numero de capas 3. impedanc econtrol enable for RF traces 4.rough placing 5.mcu pins assignemnt 6.capacitor vias placing 7.tigh palcing adicnales 8.tear drop for rf remove unsued pads to reduce cutouts 10.set place fiel origin and grid orgin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
net classes /RF* MPN and MP , distruibur link on the csv boom
Falta poner los calculos
Fiducial markers maybe
tolerancia de la resistencias
placing of vias arounf the board to confine RF deterine by the maxiunmn frerqncy content
1.Board setup 1.1 quitar capas queno se usan 2.escoger el numero de capas 3. impedanc econtrol enable for RF traces 4.rough placing 5.mcu pins assignemnt 6.capacitor vias placing 7.tigh palcing adicnales 8.tear drop for rf remove unsued pads to reduce cutouts
1.place symbols and nets 2.assign some footprints ESPACIAL PARTS EJM:ICS MPN and Manufacturer 3.RUN ERC 4. assign all footprints 5. terminar de colocar los pines de GPIOS del MCU 6. asignar Nets
comprar los componetes afltantes aparte
copper pour clse to impednac controlled traces at least 3h dielectric, so it doesnt affect
grid sizez 1.0mm rogh positning 0.1mm fine tunning

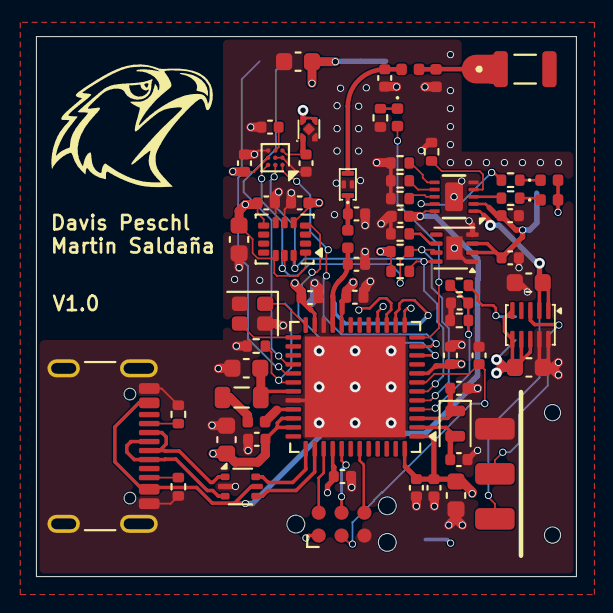
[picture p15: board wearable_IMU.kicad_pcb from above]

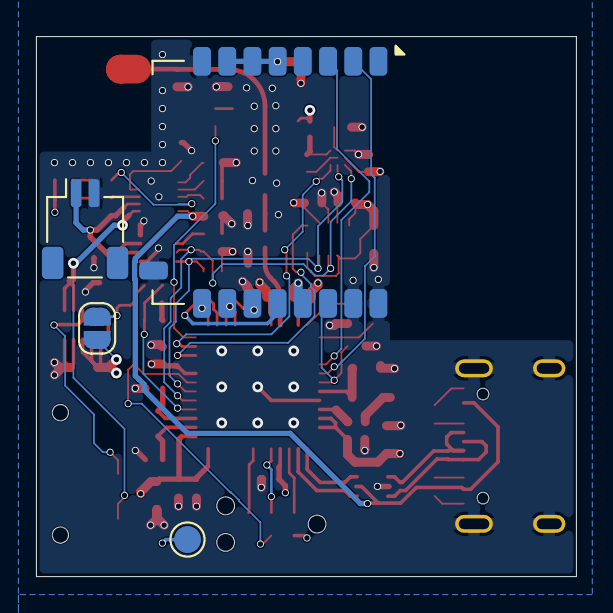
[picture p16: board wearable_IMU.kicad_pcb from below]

Board: 4 copper layers, 30.0 x 30.0 mm, 72 parts (4 on the bottom side), 53 nets.

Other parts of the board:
G1: LOGO; IIT

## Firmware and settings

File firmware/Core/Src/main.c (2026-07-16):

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
/* Includes ------------------------------------------------------------------*/
#include "main.h"
#include "usb_device.h"

/* USER CODE BEGIN Includes */
#include "usbd_cdc_if.h"
#include <stdio.h>
#include <string.h>
#include "lsm6dsv16bx_reg.h"
#include "bmm350.h"
/* USER CODE END Includes */

/* USER CODE BEGIN PD */
#define LSM6_I2C_ADDR       0x6BU   /* SDO pin high */
#define BMM350_I2C_ADDR     BMM350_I2C_ADSEL_SET_LOW   /* 0x14: ADSEL pin low */
#define SENSOR_PERIOD_MS    20      /* 50 Hz */
/* USER CODE END PD */

I2C_HandleTypeDef hi2c1;

SPI_HandleTypeDef hspi1;

/* USER CODE BEGIN PV */
static stmdev_ctx_t lsm6_ctx;
static uint8_t lsm6_addr = LSM6_I2C_ADDR;
static struct bmm350_dev bmm350;
static uint8_t bmm350_addr = BMM350_I2C_ADDR;
/* USER CODE END PV */

void SystemClock_Config(void);
void PeriphCommonClock_Config(void);
static void MX_GPIO_Init(void);
static void MX_SPI1_Init(void);
static void MX_I2C1_Init(void);
/* USER CODE BEGIN 0 */

/* ── LSM6DSV16BX I2C callbacks ──────────────────────────────────────────── */
static int32_t lsm6_i2c_write(void *handle, uint8_t reg, const uint8_t *data, uint16_t len)
{
    uint8_t addr = *(uint8_t *)handle;
    HAL_StatusTypeDef st = HAL_I2C_Mem_Write(&hi2c1, (uint16_t)(addr << 1),
                                               reg, I2C_MEMADD_SIZE_8BIT,
                                               (uint8_t *)data, len, 100);
    return (st == HAL_OK) ? 0 : -1;
}

static int32_t lsm6_i2c_read(void *handle, uint8_t reg, uint8_t *data, uint16_t len)
{
    uint8_t addr = *(uint8_t *)handle;
    HAL_StatusTypeDef st = HAL_I2C_Mem_Read(&hi2c1, (uint16_t)(addr << 1),
                                              reg, I2C_MEMADD_SIZE_8BIT,
                                              data, len, 100);
    return (st == HAL_OK) ? 0 : -1;
}

static void lsm6_delay_ms(uint32_t ms)
{
    HAL_Delay(ms);
}

/* ── BMM350 I2C callbacks ────────────────────────────────────────────────── */
static BMM350_INTF_RET_TYPE bmm350_i2c_read(uint8_t reg_addr, uint8_t *reg_data, uint32_t len, void *intf_ptr)
{
    uint8_t addr = *(uint8_t *)intf_ptr;
    HAL_StatusTypeDef st = HAL_I2C_Mem_Read(&hi2c1, (uint16_t)(addr << 1),
                                              reg_addr, I2C_MEMADD_SIZE_8BIT,
                                              reg_data, (uint16_t)len, 100);
    return (st == HAL_OK) ? BMM350_OK : BMM350_E_COM_FAIL;
}

static BMM350_INTF_RET_TYPE bmm350_i2c_write(uint8_t reg_addr, const uint8_t *reg_data, uint32_t len, void *intf_ptr)
{
    uint8_t addr = *(uint8_t *)intf_ptr;
    HAL_StatusTypeDef st = HAL_I2C_Mem_Write(&hi2c1, (uint16_t)(addr << 1),
                                               reg_addr, I2C_MEMADD_SIZE_8BIT,
                                               (uint8_t *)reg_data, (uint16_t)len, 100);
    return (st == HAL_OK) ? BMM350_OK : BMM350_E_COM_FAIL;
}

static void bmm350_delay_cb(uint32_t period_us, void *intf_ptr)
{
    (void)intf_ptr;
    HAL_Delay((period_us + 999U) / 1000U);
}

/* ── CDC transmit with busy-retry ───────────────────────────────────────── */
static void cdc_send(uint8_t *buf, uint16_t len)
{
    uint8_t retries = 10;
    while (CDC_Transmit_FS(buf, len) == USBD_BUSY && retries--)
        HAL_Delay(1);
}

/* ── Sensor initialisation ──────────────────────────────────────────────── */
static void sensors_init(void)
{
    /* ── LSM6DSV16BX at 0x6B ── */
    lsm6_ctx.write_reg = lsm6_i2c_write;
    lsm6_ctx.read_reg  = lsm6_i2c_read;
    lsm6_ctx.mdelay    = lsm6_delay_ms;
    lsm6_ctx.handle    = &lsm6_addr;

    uint8_t who_am_i = 0;
    lsm6dsv16bx_device_id_get(&lsm6_ctx, &who_am_i);
    /* Expected: 0x71. If wrong, check SDO pin / I2C address. */

    lsm6dsv16bx_reset_set(&lsm6_ctx, LSM6DSV16BX_RESTORE_CTRL_REGS);
    lsm6dsv16bx_reset_t rst;
    do { lsm6dsv16bx_reset_get(&lsm6_ctx, &rst); } while (rst != LSM6DSV16BX_READY);

    lsm6dsv16bx_block_data_update_set(&lsm6_ctx, PROPERTY_ENABLE);
    lsm6dsv16bx_xl_data_rate_set(&lsm6_ctx, LSM6DSV16BX_XL_ODR_AT_120Hz);
    lsm6dsv16bx_xl_full_scale_set(&lsm6_ctx, LSM6DSV16BX_2g);
    lsm6dsv16bx_gy_data_rate_set(&lsm6_ctx, LSM6DSV16BX_GY_ODR_AT_120Hz);
    lsm6dsv16bx_gy_full_scale_set(&lsm6_ctx, LSM6DSV16BX_2000dps);

    /* ── BMM350 at 0x14 ── */
    bmm350.intf_ptr  = &bmm350_addr;
    bmm350.read      = bmm350_i2c_read;
    bmm350.write     = bmm350_i2c_write;
    bmm350.delay_us  = bmm350_delay_cb;

    bmm350_init(&bmm350);
    bmm350_set_odr_performance(BMM350_DATA_RATE_100HZ, BMM350_AVERAGING_4, &bmm350);
    bmm350_enable_axes(BMM350_X_EN, BMM350_Y_EN, BMM350_Z_EN, &bmm350);
    bmm350_set_powermode(BMM350_NORMAL_MODE, &bmm350);
}

/* USER CODE END 0 */

/**
  * @brief  The application entry point.
  * @retval int
  */
int main(void)
{

  /* MCU Configuration--------------------------------------------------------*/

  /* Reset of all peripherals, Initializes the Flash interface and the Systick. */
  HAL_Init();

  /* Configure the system clock */
  SystemClock_Config();

  /* Configure the peripherals common clocks */
  PeriphCommonClock_Config();

  /* Initialize all configured peripherals */
  MX_GPIO_Init();
  MX_SPI1_Init();
  MX_I2C1_Init();
  MX_USB_Device_Init();
  /* USER CODE BEGIN 2 */
  HAL_Delay(2000); /* wait for USB CDC to enumerate on host */
  sensors_init();
  /* USER CODE END 2 */

  /* Infinite loop */
  /* USER CODE BEGIN WHILE */
  while (1)
  {
    /* USER CODE END WHILE */

    /* USER CODE BEGIN 3 */
    static uint32_t tick = 0;
    int16_t raw_xl[3], raw_gy[3];
    struct bmm350_mag_temp_data mag;
    lsm6dsv16bx_data_ready_t drdy;
    char buf[128];
    int len;

    /* Heartbeat LED on PA3: 100ms on, 900ms off */
    tick++;
    if (tick == 1)
        HAL_GPIO_WritePin(GPIOA, GPIO_PIN_3, GPIO_PIN_SET);
    else if (tick >= 5)  /* 5 * 20ms = 100ms */
    {
        HAL_GPIO_WritePin(GPIOA, GPIO_PIN_3, GPIO_PIN_RESET);
        if (tick >= 50)  /* 50 * 20ms = 1000ms */
            tick = 0;
    }

    lsm6dsv16bx_flag_data_ready_get(&lsm6_ctx, &drdy);
    if (drdy.drdy_xl)
        lsm6dsv16bx_acceleration_raw_get(&lsm6_ctx, raw_xl);
    if (drdy.drdy_gy)
        lsm6dsv16bx_angular_rate_raw_get(&lsm6_ctx, raw_gy);

    bmm350_get_compensated_mag_xyz_temp_data(&mag, &bmm350);

    /* Serial Studio frame: start=SLASH*, end=*SLASH, comma-separated
     * Channels: ax ay az (raw LSB)  gx gy gz (raw LSB)  mx my mz (uT) */
    len = snprintf(buf, sizeof(buf),
                   "/*%d,%d,%d,%d,%d,%d,%.2f,%.2f,%.2f*/\r\n",
                   raw_xl[0], raw_xl[1], raw_xl[2],
                   raw_gy[0], raw_gy[1], raw_gy[2],
                   (double)mag.x, (double)mag.y, (double)mag.z);
    if (len > 0)
        cdc_send((uint8_t *)buf, (uint16_t)len);

    HAL_Delay(SENSOR_PERIOD_MS);
  }
  /* USER CODE END 3 */
}

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


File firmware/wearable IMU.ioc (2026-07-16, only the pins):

Mcu.UserName=STM32WB55CEUx
PA1.Signal=GPIO_Input
PA11.Signal=USB_DM
PA12.Signal=USB_DP
PA13.Signal=SYS_JTMS-SWDIO
PA14.Signal=SYS_JTCK-SWCLK
PA2.Signal=GPIO_Input
PA3.Signal=GPIO_Output
PA4.Signal=GPIO_Output
PA5.Signal=SPI1_SCK
PA6.Signal=SPI1_MISO
PA7.Signal=SPI1_MOSI
PB0.Signal=GPIO_Output
PB1.Signal=GPIO_Output
PB3.Signal=SYS_JTDO-SWO
PB8.Signal=I2C1_SCL
PB9.Signal=I2C1_SDA
PC14-OSC32_IN.Signal=RCC_OSC32_IN
PC15-OSC32_OUT.Signal=RCC_OSC32_OUT
PE4.Signal=GPIO_Input

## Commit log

2026-06-05 scaffold: full project structure with stub files
    Monorepo layout per README §8: docs (01–08), hardware/v1.0 folders,
    firmware/node stubs (App/Drivers/Comms/Sensors/Power + config.h),
    host Python package (ingest/sync/orientation/kinematics/ekf/viz/sim),
    tools/, calibration/, test-rig/. Git-versioned on main.
2026-07-16 Replace scaffolded firmware/hardware stubs with real v1.0 implementation
    Firmware: real STM32CubeIDE/CubeMX project for the STM32WBA55 (Core/,
    Drivers/, Middlewares/, ThirdParty/ vendor drivers for BMM350 and
    LSM6DSV16BX, USB device stack) replaces the earlier hand-scaffolded
    firmware/node/{App,Comms,Drivers,Sensors,Power} stub layout, which was
    all placeholder TODOs with no logic.
    Hardware: real KiCad v1.0 PCB (schematic/layout/fab outputs) and
    mechanical CAD (enclosure STL/STEP, assembly renders) replace the
    placeholder hardware folders.
    Host: wire-protocol codec + tests (ingest/protocol.py, host/tests/),
    and reader/generator updated to emit/consume real wire bytes instead
    of a placehold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
    [BOM-wearable_IMU.csv, CASE.stl, case1.stl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]
2026-07-16 Update documentation to match real v1.0 hardware and firmware status
    Corrects docs that had drifted from what was actually built/fabricated:
    - Magnetometer: MMC5983MA -> BMM350 (confirmed against the fabricated
    PCB's JLCPCB BOM, which lists BMM350).
    - IMU + magnetometer are I2C (addr 0x6B and 0x14), not SPI; only the
    DWM3000 UWB module is SPI. Fixes 04-firmware.md's driver-notes
    section, which described a SPI port abstraction for both sensors.
    - Debug/data connection is a TC2030-IDC footprint (bare pogo-pin pads
    on the PCB, mates with a separate Tag-Connect cable/clip) rather
    than a soldered 10-pin header, matching the JLCPCB BOM (no connector
    line item, consistent with a pad-onl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
2026-07-16 Note test-rig hardware gaps and onboarding-doc TODO in roadmap
    Records rig-side gaps reported from the lab: no end-effector adapter
    exists yet to mount a wearable IMU node on the rig, a modified/"fork"
    wearable IMU variant built for rig-mounting exists but isn't in this
    repo yet, and the rig's `arm` piece needs a reprint. Also flags that
    the onboarding doc for new students (STM32CubeProgrammer flashing/FUS
    update, Serial Monitor Pro) is still unwritten.
2026-07-17 Correct MCU part, remove nonexistent flash IC, defer undecided estimates
    Verified against the fabricated PCB's BOM (jlcpcb/production_filesV1.0/
    BOM-wearable_IMU.csv) rather than trusting prior doc claims:
    - MCU is STM32WB55CEUx (dual-core Cortex-M4 + Cortex-M0+, BLE 5.4,
    512 KB flash, 256 KB SRAM, native USB), not STM32WBA55CG as every
    doc previously claimed. Corrects the "no native USB, charging only"
    claim too — native USB is present and a USB CDC stack already exists
    in firmware/USB_Device/. Flagged (not resolved) that the sensor
    bring-up smoke test is likely read over USB-CDC rather than SWO,
    which needs reconciling with the SWD/SWO wired-data-path assumption
    used throu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
2026-07-17 Add fab-process/BOM/tools stubs, generalize PC specs, fix battery connector
    - Documents the PCB fabrication process explicitly (JLCPCB PCBA via the
    KiCad fabrication-toolkit plugin) in hardware/electronics/v1.0/README.md
    — this was previously only implicit from folder naming.
    - Adds BOM templates for the wearable case and the rig
    (hardware/mechanical/v1.0/, test-rig/hardware/mechanical/v1.0/) — no
    mechanical BOM existed anywhere; these are explicitly marked as
    needing the real parts list, not fabricated content. Also flags the
    CASE.stl vs case1.stl ambiguity (unclear which is current).
    - Adds docs/09-tools.md, an incomplete starting list of build tools
    (wire stripper confir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
2026-07-17 Drop unused case STLs, simplify pending BOM/fab sections, trim tools list
    - Removes CASE.stl and case1.stl (not needed) and updates the mechanical
    README to reflect that no printable enclosure file currently exists in
    the repo — the assembly renders still document the design.
    - Simplifies the case and rig BOM/fabrication sections to a short
    "Pending — see 07-roadmap.md" pointer instead of duplicating template
    tables in three places.
    - Removes wire stripper from docs/09-tools.md (not actually needed).
    [CASE.stl, case1.stl]
2026-07-17 Remove stale battery-capacity open item — already decided at 120 mAh
    README §11 still listed battery capacity as an open 300-600 mAh
    decision, contradicting the BOM table (§4) and docs/07-roadmap.md,
    which both correctly already state 120 mAh.
2026-07-17 Trim README Node BOM table to architecturally significant parts only
    MCU, IMU, magnetometer, UWB — the parts that shape the system design.
    Power management, connectors, battery, and indicator LED were
    duplicating hardware/electronics/v1.0/README.md's BOM-sourced parts
    table; linked there instead of repeating it.
2026-07-17 Trim redundant/stale README content
    - Intro no longer frames the doc as a "hand to Claude Code to scaffold
    and build" brief — the project is built; it's just the source of truth
    now. Drops the dead forward-link to "How to use this document".
    - "How to use this document" slimmed to the source-of-truth + Pandoc
    note. Removed the stale scaffolding step (with its broken
    #8-repository-structure-proposed anchor) and two points that
    duplicated §7 (build order) and §11 / the top-of-doc note (roadmap
    pointer, which was appearing three times).
    - Dropped the §3 flash-IC sentence — it explained an absence already
    covered by the RAM-buffer note two lines down and by §9.
    - Tightened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
2026-07-17 Drop redundant "Where the work happens" pipeline diagram
    Its front-end (nodes -> master -> PC) repeated the Primary topology
    diagram directly above it, and its back-end (PC pipeline stages)
    repeated the §6 processing-pipeline table. Kept the "v1 needs no
    Kalman filter" callout and added a cross-link from the topology
    bullets to §6 for the stage detail.
2026-07-17 Remove the dongle concept entirely (nRF52840 BLE + UWB backup dongle)
    Drops all mention of a separate BLE receiver dongle and the UWB-USB
    backup-uplink dongle across the repo. Reworked the architecture text
    so it stands on its own: BLE (host-native, PC's own Bluetooth) is the
    sole wireless uplink to the PC; UWB stays on-body only (node -> master
    transport, time sync, ranging). Wired (SWD/SWO or USB CDC) remains the
    dev/recovery path. Removed the now-empty "Dongle" open item and the
    "UWB backup dongle: build or defer" roadmap task.

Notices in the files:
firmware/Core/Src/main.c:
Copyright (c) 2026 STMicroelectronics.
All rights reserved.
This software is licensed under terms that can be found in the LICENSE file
